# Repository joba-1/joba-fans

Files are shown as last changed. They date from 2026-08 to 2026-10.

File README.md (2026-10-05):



# joba-fans — quiet, networked fans for radiators

A small system that puts **PC fans on top of panel radiators** and controls them over WiFi. Its job is
to make a heat pump that cools through wall-hung radiators work properly: a low-mounted radiator hardly
emits any cooling power by free convection, so the heat pump short-cycles. Forced air over the fins
recovers a factor of roughly 3–4 (reasoning and sizing: [fan-mount/docs/requirements.md](fan-mount/docs/requirements.md)).

Four parts, each in its own directory with its own README:

| Part | What it is | Technology |
|---|---|---|
| [`fan-controller/`](fan-controller/) | The board: four PWM fan channels with tach read-back on a socketed ESP32 module | KiCad 10, Python generators |
| [`fan-housing/`](fan-housing/) | A snap-fit 3D-printed case for that board | OpenSCAD |
| [`fan-remote/`](fan-remote/) | The firmware: web remote, MQTT, Home Assistant discovery, soft start | PlatformIO / Arduino-ESP32 |
| [`fan-mount/`](fan-mount/) | 3D-printed mounts that hold 120 mm fans on the radiators | FreeCAD, STL |

## How it fits together

```mermaid
flowchart LR
  subgraph radiator["Radiator"]
    F["PC fans, 120 mm, 4-pin PWM<br/>in <b>fan-mount</b> parts"]
  end
  subgraph box["<b>fan-housing</b> (printed case)"]
    B["<b>fan-controller</b> board<br/>XIAO ESP32-C3<br/>running <b>fan-remote</b>"]
  end
  PSU["12 V supply"] --> B
  B -- "PWM 25 kHz, +12 V<br/>tach back" --> F
  B <-- "WiFi" --> N["Browser (web remote)<br/>MQTT broker + Home Assistant"]
  N -.-> HP["heat-pump / room control<br/>(outside this repo)"]
```

* A **radiator** carries up to ~9 fans in `fan-mount` parts. The fans are standard 120 × 25 mm PC fans.
* Each **controller board** drives four channels; several fans can share a channel (same speed, one tach).
  A 12 V supply feeds the board, which passes 12 V on to the fans.
* The **firmware** gives each board a web page, MQTT topics and a Home Assistant device. Speeds are set
  there — by hand, or by automation (for instance a heat-pump cooling signal in Home Assistant). The
  temperature logic is deliberately *not* part of this repo; the firmware only exposes the fans.
* The **housing** protects the board and brings the barrel jack, USB-C port and four fan cables out.

### The interfaces, and how each was checked

| Interface | Contract | Checked |
|---|---|---|
| firmware ↔ board | FAN1–4: PWM on D1/D3/D7/D6, tach on D2/D4/D10/D5 (GPIO 3/5/20/21 and 4/6/10/7) | The pin table in `fan-remote/src/Fans.cpp` equals the pad nets read out of `fan-controller.kicad_pcb`; the firmware builds for the XIAO ESP32-C3 and C6 and its 22 unit tests pass |
| board ↔ fans | 4-pin PC fan, pinout GND / +12 V / tach / PWM, 25 kHz PWM, 3.3 V logic | Pinout equals the PCB nets of J2–J5; 25 kHz is what the firmware generates. Total current of all fans must stay below the 1.5 A polyfuse |
| board ↔ housing | outer dimensions, connector positions, USB-C end, jack overhang | `fan-housing/board_params.scad` is regenerated from the PCB and is identical; `check_fit.py` passes (latch strain 1.5 %, ≥ 2.2 mm of air above every part, no tab hits a component); the STLs match the OpenSCAD source; the USB-C cut-out sits at the module's USB end (the module's pad rows run along the board's short side, with D6/D7 and the antenna at the other end) |
| fans ↔ mounts | 120 mm fan, 25 mm thick, 105 mm hole pattern | Collar inside 120.6 mm, rest height 2 mm, collar 28 mm; STL sizes match the spreadsheet dimensions (226.6 × 126.6 × 28 mm) |
| firmware ↔ Home Assistant | MQTT discovery, topics `fan-control/<id>/…` | Tested on a bench board with HA (see `fan-remote/docs/test.md`) |
| housing ↔ mounts | none (they only meet through the fans and cables) | — |

Fitting the parts together turned up four things worth knowing; all are written down in the component
READMEs:

1. The fan headers on the board are **unshrouded** — a reversed connector puts 12 V on a tach line
   ([fan-controller](fan-controller/README.md#known-issues)).
2. The PWM lines **float during an ESP reset**, so fans can burst briefly (also fan-controller; a pull-down
   is a candidate for board revision 2).
3. A radiator needs **more fans than a board has channels**, so fans must be chained per channel
   ([fan-mount](fan-mount/README.md#how-it-fits-the-rest-of-the-system)); this has not been tried yet.
4. The firmware has not yet run **on the real board** — only on a bench XIAO with one fan.

## Building it

1. **Board.** Order from the files in [`fan-controller/fab/`](fan-controller/fab/) (a PCB service that does
   assembly; revision 1 went to PCBWay), or regenerate them with `fan-controller/scripts/make_fab.sh`.
   Plug a XIAO ESP32-C3 into the sockets.
2. **Case.** Print the three STLs from [`fan-housing/stl/`](fan-housing/stl/) (PETG, no supports).
3. **Mounts.** Pick the variant for your radiator in [`fan-mount/cad/`](fan-mount/cad/) (the radiator
   sheet geometry is in [`fan-mount/docs/measurements.md`](fan-mount/docs/measurements.md)) and print it in
   PETG. Measure your own radiator first if it differs from the three documented ones.
4. **Firmware.** Register the board and flash it over USB-C, then set WiFi and the MQTT broker in the
   board's setup portal — see [`fan-remote/README.md`](fan-remote/README.md).
5. **Assemble.** Fans into the mounts and onto the radiator, fan cables into the board's headers (check
   that pin 1 = GND), board into the case, 12 V in.

## Repository layout

```text
fan-controller/   KiCad project, generator scripts, fab/ (fabrication package), docs/ (build log)
fan-housing/      OpenSCAD case, STLs, fit check
fan-remote/       PlatformIO firmware, tests, docs/ (spec, user, admin, test)
fan-mount/        FreeCAD models, STLs, scripts, docs/ (requirements, measurements, design notes)
assets/           logo (the fan symbol, also used as favicon) and social-preview image
LICENSE           CC BY-SA 4.0
```

Naming: the directories are named by role. The firmware names itself `fan-control-N` on the network (host
name, MQTT topics, Home Assistant ids) — that is the *device* identity, kept stable for boards that are
already installed, and is not the directory name.

## History and versions

Earlier, the board, the radiator mounts and the firmware lived in separate places. The commit history of
all of them is preserved here, now under the new directory names (messages are left in the language they were
written in, mostly German in the mounts' early history). Commit hashes changed in the merge, so documents
refer to **tags** instead:

| Tag | Meaning |
|---|---|
| `fan-controller-v1` | the board layout that was ordered (schematic and PCB unchanged since) |
| `fan-remote-v1.1.0` | firmware 1.1.0 (the firmware's build info is derived from `fan-remote-v*` tags) |

## Language and licence

Documentation and code comments are in English. Exceptions: the firmware's web page is bilingual
(German/English, by browser language), and the FreeCAD spreadsheets in `fan-mount/cad/` use German parameter
names (glossary in [fan-mount/docs/design-notes.md](fan-mount/docs/design-notes.md)).

[CC BY-SA 4.0](LICENSE). The XIAO symbol and footprints in `fan-controller/libraries/` come from Seeed
Studio's OPL_Kicad_Library, also CC BY-SA 4.0. The firmware pulls in third-party libraries through
PlatformIO under their own licences.

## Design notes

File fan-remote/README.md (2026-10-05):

# fan-remote

Firmware for the four-channel fan controller board in [`../fan-controller/`](../fan-controller/) (XIAO
ESP32-C3), part of the [joba-fans](../README.md) project. One board drives four 4-pin PC fans with 25 kHz
PWM and reads their RPM.

**Status:** version 1.1.0 (git tag `fan-remote-v1.1.0`), running on two boards. Unit tests pass on the PC and the image builds for
the XIAO ESP32-C3 (the module the board is designed for) and the pin-compatible ESP32-C6. It has been run
on a bench C6 with one fan; the hardware bring-up on the real fan board is still open (see
[docs/test.md](docs/test.md)). The pin table matches the board's pad nets.

* **Web remote** on every board (`http://fan-control-1/`): live RPM, on/off, preset
  speeds, a free slider, per fan and for all fans. Phone first, German and English.
* **Safe, quiet start.** The duty is raised slowly until the tach shows the fan
  turning, then slewed to the target; a blocked fan is detected and retried with
  backoff instead of being driven hard.
* **MQTT** with **Home Assistant discovery**; any number of boards, one image.
* **Each board has its own colour** on the web page (from its number), so several controllers can be told apart.
* **Status LED** where the module has one (XIAO ESP32-C6): fans on/off and a health signal, dimmed at night, or dark.
* Fans keep running without WiFi, broker or browser: control runs in its own task.

```text
docs/spec.md    architecture, decisions and their reasons, topic reference
docs/user.md    using the web page and Home Assistant
docs/admin.md   building, flashing, provisioning, operations, troubleshooting
docs/test.md    test plan and the hardware bring-up checklist
```

## Quick start

```sh
pio test -e native      # unit tests, no hardware
pio run -e xiao_c3 -t upload   # first flash over USB-C
```

Boards are numbered in `devices.csv` (MAC → number): register a new one first, then flash.
The number is the host name (`fan-control-N`), the MQTT topic and the Home Assistant id.

```sh
python3 scripts/register_device.py --port /dev/ttyACM0     # prints fan-control-N
```

The first build creates `config.ini` (gitignored) with a random admin password and prints it.
That one password does the settings login, the setup access point and OTA. A fresh board opens the access point
`fan-control-N-setup`; join it and enter WiFi, name and broker. Later updates go over WiFi:

```sh
pio run -e ota -t upload --upload-port fan-control-1     # no firewall port needed
```

Details in [docs/admin.md](docs/admin.md).

## Layout

| Path | |
|---|---|
| `lib/FanCore/` | hardware-free logic (state machine, speed mapping, RPM): unit tested |
| `src/` | firmware: `Fans` (PWM, tach, task), `Web`, `Mqtt`, `Net`, `NetLog`, `Settings` |
| `web/` | the page (`index.html`, gzipped and embedded at build time) and `logo.svg` |
| `scripts/mock_server.py` | fake device API to work on the page without hardware |
| `test/` | Unity tests |

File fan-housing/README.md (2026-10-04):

# fan-housing — case for the 4-channel fan controller

A snap-fit case for the [`fan-controller`](../fan-controller/) board, no screws. Outer size
**78.5 × 30.6 × 28.2 mm**, parametric in OpenSCAD.

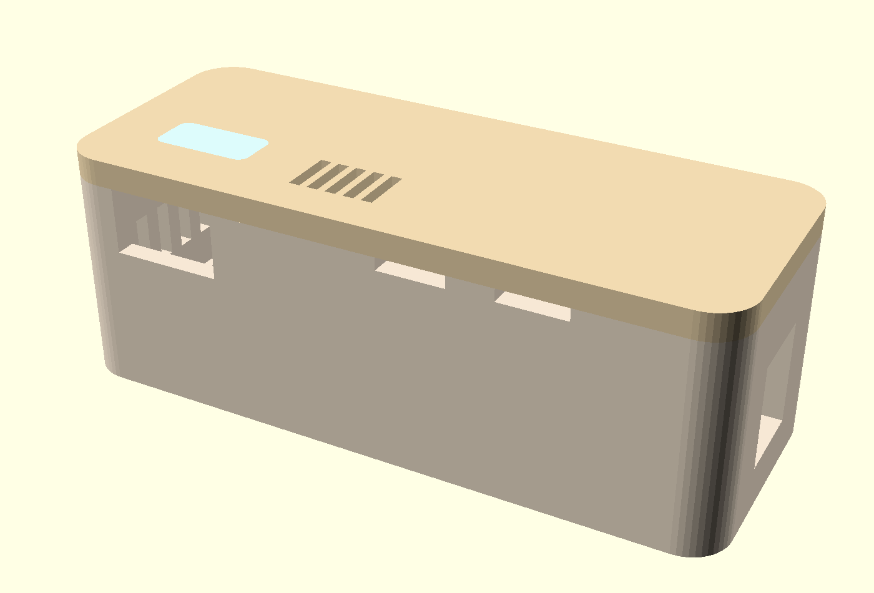
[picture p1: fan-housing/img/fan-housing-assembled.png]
Closed case


At the front the two cable slots for FAN1 and FAN2 and, to the left of them, the USB-C cut-out; at the
right the barrel jack; on top the light window and the vent slots above the voltage regulator. The other
two cable slots are mirrored on the back.

Generated from `fan-housing.scad`; all board dimensions come from `board_params.scad`, which
`extract_geometry.py` pulls out of the `.kicad_pcb`. The board is ordered and its dimensions are fixed —
only the case changes from here on.

## Parts

| File | Material | Position on the bed |
|---|---|---|
| `stl/fan-housing-tray.stl` | cream PETG | as exported, floor down; has four **mouse ears** (see below) |
| `stl/fan-housing-lid.stl` | cream PETG | as exported, visible face down, tabs up |
| `stl/fan-housing-guide.stl` | transparent PETG | as exported |

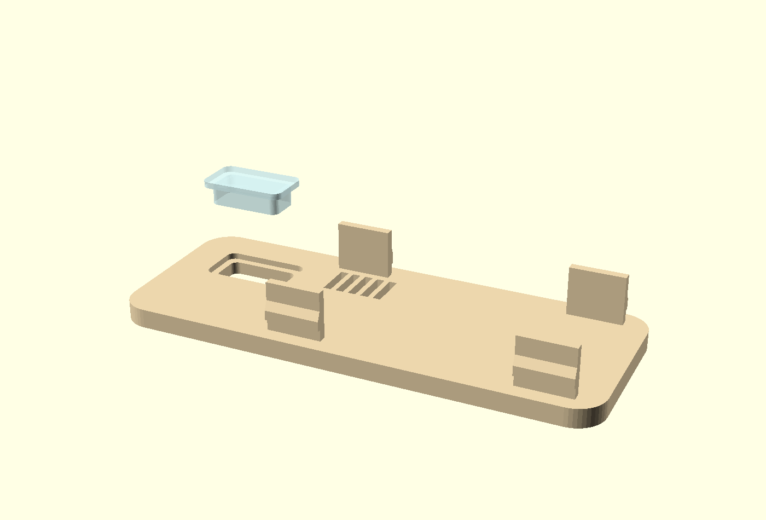
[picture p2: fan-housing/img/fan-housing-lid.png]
Lid in print orientation with light guide


The lid in print orientation — upside down, the four spring tabs pointing up. The latch nose can be seen
as a step on the two front ones; the chamfer below it pushes the tab in by itself when the lid is put on.

The light guide is shown lifted off and is **printed separately** — transparent, while the lid stays
cream. It is inserted from the inside of the lid, in this upside-down position from above. Its collar then
rests against the underside of the lid and keeps it from falling out.

**Printing lid and light guide in one multi-colour job** works, with two caveats found the hard way. The slicer
refuses the job (`gcode path conflicts … found slicing result conflict`) if the guide's collar overhangs the window by
more than about 1 mm (`guide_collar_o`, now 1.0), and — for reasons not understood — also for some positions on the
plate (e.g. at the far front right). Keep lid and guide as one group, so they keep their positions to each other, and
check that the slicer accepts the placement; turning the lid and guide together by 90° and putting them left of the
tray did it here.

All three are already exported in print orientation and need **no supports**. The lid lies upside down so
the visible face comes smoothly off the bed and the latch tabs point up.

Recommendation: 0.2 mm layers, 4 perimeters, and a **large brim** for the tray (8–10 mm, or keep the
mouse ears and add a brim around them). The four perimeters are not cosmetic — the spring tabs are
1.4 mm thick and should consist of perimeters, not infill.

## Assembly

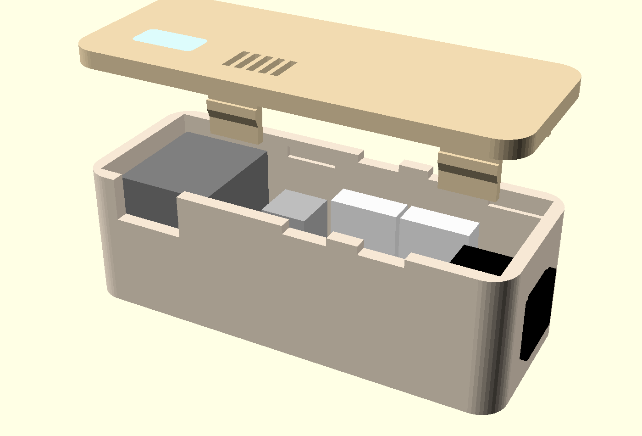
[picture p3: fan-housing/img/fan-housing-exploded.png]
Exploded view


1. Press the light guide into the lid opening from the **inside**. The collar holds it against the
   underside of the lid; it sits tight, but a drop of glue on the collar does no harm.
2. Put the board into the tray from above; it rests on the surrounding shoulder. 2.5 mm remain under it for
   the solder joints.
3. Plug in the fan connectors and lay the cables into the notches of the long walls. The notches are open
   at the top so that you lay the cables in instead of threading them — the connector does not fit through
   a closed hole. They are only 1.5 mm deep: the lid holds the cable lightly, which is also the strain relief.
4. Press the lid on until the four noses click in. To open, press the long walls outward a little at the
   latch points (at X 27.5 and 67 mm).

## Openings

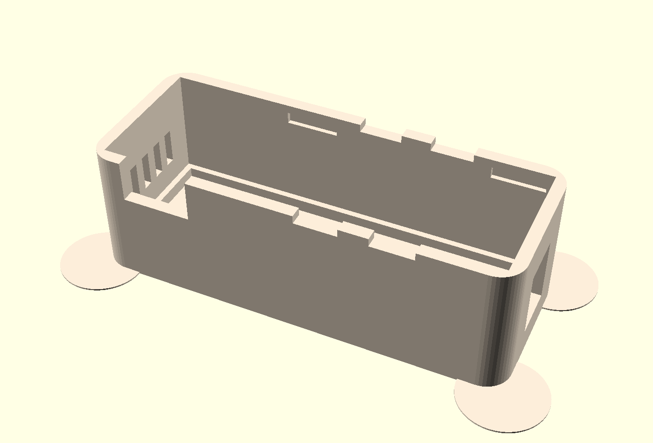
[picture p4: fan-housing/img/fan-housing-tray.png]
Tray from the inside


The inside is **sharp-cornered**, like the board (only the outside is rounded). The board has 0.4 mm
clearance (`fit`) to the walls on all four sides. Inside, the support shoulder for the board runs all around; below it 2.5 mm remain for the solder joints.
At the top of the long walls sit the four latch pockets as shallow recesses — they only mill into the wall,
a through-cut would be visible from outside. On the left the vent slots.

* **Barrel jack:** right end wall. It overhangs the board edge anyway and so sticks out of the wall. The
  opening is the jack's width minus `jack_trim` = 1.4 mm on each side.
* **Four cable notches**, 8 mm wide and 1.5 mm deep (`notch_depth`; the cable is 0.9 mm), above the fan connectors in the long
  walls. The lid closes them at the top; the cable is then captive.
* **USB-C** in the lower long wall, for re-flashing without opening: a closed window `usb_h` = 8 mm high
  (the plug's overmold, not just the 3.3 mm receptacle, has to fit), 13 mm wide, centred on the receptacle
  of the socketed XIAO. Can be switched off with `usb_opening = false`.
* **Vent slots** in the left end wall and in the lid above the AMS1117. At a 12 V input it dissipates about
  0.7 W; in a tight box this size that becomes noticeable. Can be switched off with `vents = false`.
* **Light window** in the lid above the XIAO — see below.

## Keeping the tray on the bed

A long, tall, thin-walled PETG tray shrinks while it cools and peels up at its ends. Two measures, one by
construction and one in the slicer:

* **Mouse ears** (`ears = true`): four 8 mm radius, one-layer (0.3 mm) discs centred on the bottom corners
  of the tray — they are part of `fan-housing-tray.stl` and add bed contact exactly where the lifting starts.
  Cut them off with a knife after printing; the tray's own walls are untouched. Set `ears = false` and
  re-export for a clean model.
* **A large brim** (8–10 mm) on top of that, a clean and warm bed (PETG: ~80 °C), no part-cooling fan for
  the first layers, and no draught. If it still lifts, the next step by construction would be to open the
  floor (slots) to relieve the stress — not done yet because it also reduces the bed contact.

## Dimension chains on layer boundaries

The lid is **3.1 mm** thick, not 3.0. The reason is not visual but about printing: with a 0.3 mm first layer
and 0.2 mm layers after that, the layer boundaries are at 0.3 / 0.5 / … / 2.9 / 3.1. A top edge at 3.0 falls
in the **middle** of a layer.

This only becomes apparent where two parts meet there: the collar of the light guide begins at the inside of
the lid, and at 3.0 mm the top of the lid and the underside of the collar claim the same layer at the same
place. The slicer then aborts with `found slicing result conflict` although the geometry is clean.

It was found on the printed part: the window sat one layer too far back on the inside. With 3.1 mm the
dividing plane lies on a layer boundary and the collar can be printed along.

**Rule of thumb:** where two parts in one print meet, the dividing plane must lie on a layer boundary.
Otherwise they compete for the same layer.

## About the LED

The XIAO ESP32-C3 has **no usable LED**: neither a power nor a user LED. The only LED on the module is the
charge indicator next to the USB-C socket, and it only lights when a LiPo is charging on the BAT pads. Our
board has no battery and no LED of its own. The window therefore stays dark unless something is retrofitted.
(The firmware does not drive an LED either.)

Retrofitting takes two components. The strapping pins D0 (pin 1), D8 (pin 9) and D9 (pin 10) are free — they
were deliberately left unconnected. **D8** is the right choice:

```text
3V3 (pin 12) --- 330 ohm --- LED --->|--- D8 (pin 9)
```

The LED lights when the firmware pulls D8 LOW. GPIO8 has to be HIGH during boot — in this circuit the LED is
then off, and the resistor to 3V3 additionally acts as a weak pull-up. The other way round (LED to GND)
would disturb booting.

Pins 9 and 12 are both in the left socket strip, 7.6 mm apart. The LED itself goes on top of the XIAO module
with two thin wires, under the window. 330 ohm are lying around anyway — it is the value of R9 to R12.

If you do not want that, set `light_window = false` and get a closed lid.

## Why the lid is 3 mm thick

The walls are 2.4 mm, the lid 3.1 mm. Cream PETG is still slightly translucent at 2.4 mm; an LED directly
underneath shows as a blotch. At 3 mm all is calm, and the light exits only where it should — through the
transparent light guide.

## Check before printing

The board dimensions are exact. The component heights are measured or catalogue values: socketed XIAO
module underside 12.5 mm above the board (**measured on the real assembly**; a plain 8.5 mm header was assumed
at first), XIAO board 1.0 mm, USB-C socket 3.3 mm (catalogue), fan connector 12.0 mm (a figure supplied by
the owner), electrolytic cap 12.5 mm. That gives 19 mm of inner height with a margin of 2.2 mm above the
tallest part (the XIAO).

If a value turns out to be different: adjust `h_socket`, `h_xiao_pcb`, `h_usbc` and `inner_h` in
`fan-housing.scad`, run `check_fit.py` and export again.

## Changing and checking

```sh
python3 fan-housing/extract_geometry.py   # after a change to the board (needs KiCad's pcbnew module)
python3 fan-housing/check_fit.py          # check the fits numerically (needs openscad)
fan-housing/export_stl.sh                 # regenerate the three STLs
```

`check_fit.py` checks what a render does not show: whether the latch nose hits its pocket, whether the
spring tab withstands the deflection (outer-fibre strain below 3 %, PETG yields from about 4 %), whether a
tab pokes into a component, and whether every component fits under the lid. Two errors have already
accumulated here that were not visible in the picture: a latch pocket that cut through the wall, and a nose
that sat 2 mm below its pocket. The model works out its cuboids itself and prints them via `echo()` so that
the dimensions do not live in two places.

Verified when this repository was assembled: `board_params.scad` is identical to what the current PCB
produces, `check_fit.py` passes all checks, and the three STLs match the OpenSCAD source (same bounding box
and volume).

For viewing: `part = "all"` (the default) shows the assembly with a solid tray and a **translucent lid** — look
down through the lid at the board with its parts (socketed XIAO with its USB-C receptacle, fan connectors, jack,
capacitor) to check the openings against the real parts (`board_mock(a)` sets the board's opacity):

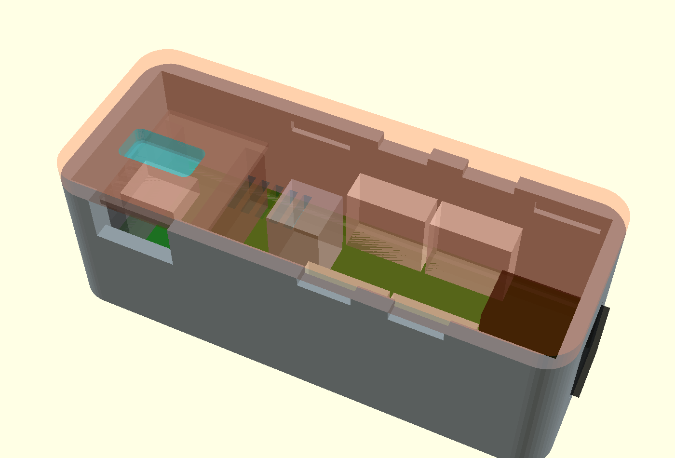
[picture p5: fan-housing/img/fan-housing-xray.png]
See-through view


Other views: `part = "explode"` shows the assembly with the lid
lifted off, `part = "closed"` the closed case, `part = "lid_guide"` the lid in print orientation with the
light guide lifted off. `part = "latch"` cuts a 5 mm thick slice across one latch and puts it at the origin
— for judging the engagement in the OpenSCAD GUI, where you can rotate freely. As a still image that is of
little use: from the inside the tab hides exactly the pocket, and the view from outside needs the CGAL
renderer, which ignores `color()`.

The pictures in `img/` are made in preview mode (without `--render`), otherwise all parts are one flat
yellow:

```sh
openscad -o img/fan-housing-assembled.png --imgsize=1400,950 \
         --camera=36.4,12.5,8,60,0,28,168 -D 'part="closed"' fan-housing.scad
```

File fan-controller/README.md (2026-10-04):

# fan-controller — 4-channel PWM fan controller board

A small two-layer board that drives **four 4-pin PC fans** (25 kHz PWM, tach read-back) from a socketed
**Seeed XIAO ESP32-C3**. 12 V in through a barrel jack, 72.9 × 25.0 mm. It is the electronics of the
[joba-fans](../README.md) project; the firmware that runs on it is [`fan-remote`](../fan-remote/), the case
is [`fan-housing`](../fan-housing/), and the fans sit in the [`fan-mount`](../fan-mount/) parts.

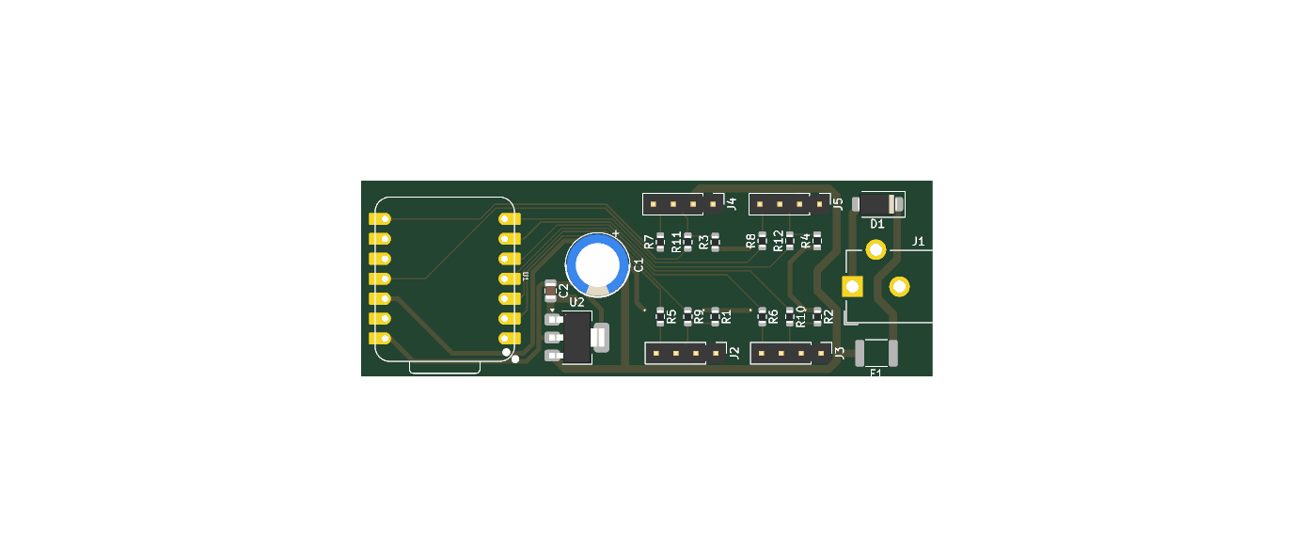
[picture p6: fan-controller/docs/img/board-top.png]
Board, top


**Status:** revision 1 (git tag `fan-controller-v1`) was ordered from PCBWay, 10 boards, fully assembled
except for the XIAO module (the story is in the [build log](docs/build-log.html)). The firmware has so far
been tested on a bench XIAO with one fan, not yet on this board — see
[`fan-remote/docs/test.md`](../fan-remote/docs/test.md).

## Circuit

Per channel the PWM goes through 1 kΩ to the fan, and the tach signal comes back through 330 Ω to the ESP,
with a 10 kΩ pull-up to 3V3. Supply is a barrel jack, an SS34 diode as reverse-polarity protection, a 1.5 A
polyfuse and an AMS1117-5.0 for the ESP (which also provides the 3V3 for the tach pull-ups). The XIAO module
is **socketed** (two 1×7 female headers), not soldered.

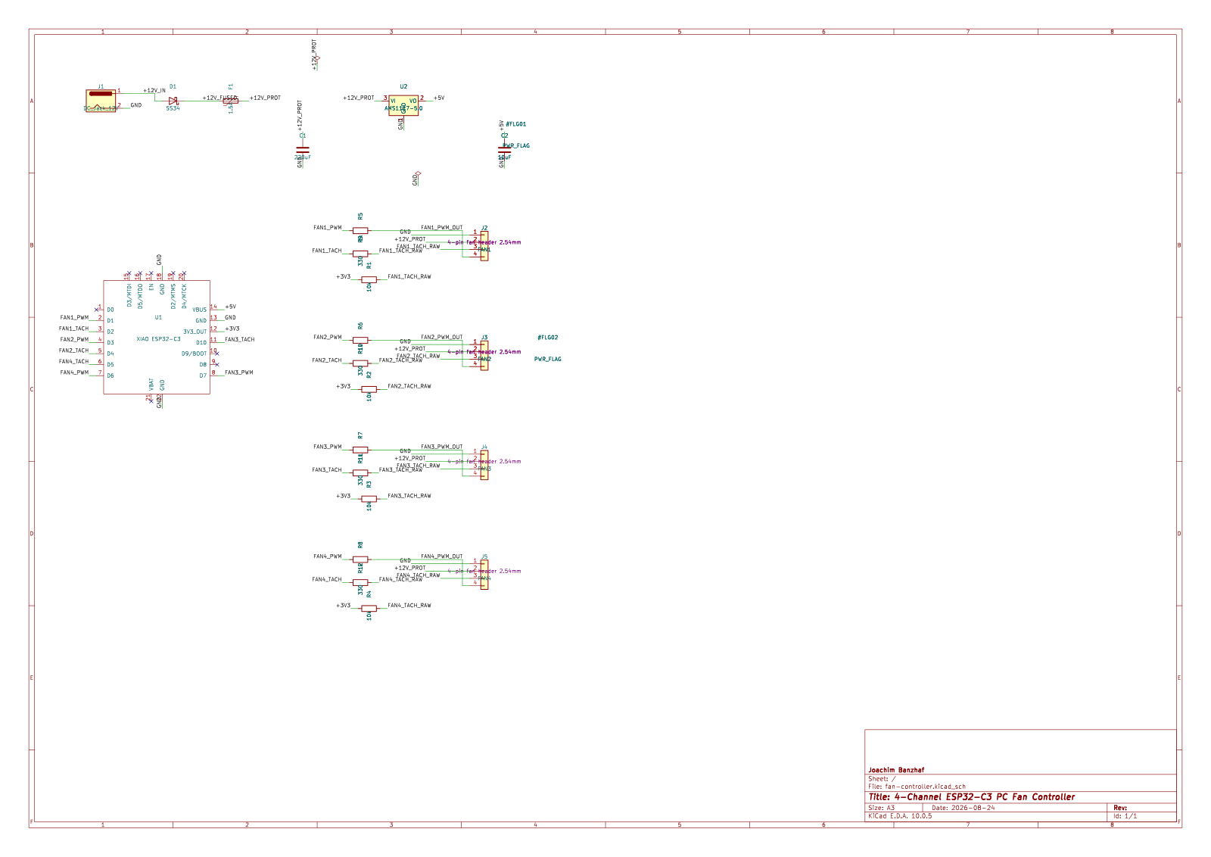
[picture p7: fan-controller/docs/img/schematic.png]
Schematic


### Pin assignment (verified against the PCB)

| Fan | Header | PWM (XIAO pin → GPIO) | Tach (XIAO pin → GPIO) |
|---|---|---|---|
| FAN1 | J2 | D1 → GPIO3 | D2 → GPIO4 |
| FAN2 | J3 | D3 → GPIO5 | D4 → GPIO6 |
| FAN3 | J4 | D7 → GPIO20 | D10 → GPIO10 |
| FAN4 | J5 | D6 → GPIO21 | D5 → GPIO7 |

D0, D8 and D9 are left free — strapping pins of the ESP32-C3 (D8 is suggested for an optional LED, see
[`fan-housing`](../fan-housing/README.md#about-the-led)). The firmware uses exactly this table
(`fan-remote/src/Fans.cpp`); both were checked against the pad nets of the `.kicad_pcb`.

Fan connector pinout (standard PC 4-pin): **1 = GND, 2 = +12 V, 3 = tach, 4 = PWM**.

| Part | Value |
|---|---|
| J1 | DC barrel jack 5.5 × 2.1 mm, 12 V, overhangs the board edge on purpose |
| D1 | SS34, reverse-polarity protection |
| F1 | 1.5 A polyfuse (1812), shared by all four fans and the regulator |
| U2 | AMS1117-5.0 for the XIAO's VBUS pin |
| C1 / C2 | 220 µF electrolytic (leaded, 3.5 mm pitch) / 10 µF 0805 |
| R1–R4 / R5–R8 / R9–R12 | 10 kΩ tach pull-up / 1 kΩ PWM series / 330 Ω tach series |
| J2–J5 | fan headers, 1×4, 2.54 mm |
| U1 | XIAO ESP32-C3 on two 1×7 female headers (the XIAO ESP32-C6 is pin-compatible) |

## Files

| Path | Content |
|---|---|
| `fan-controller.kicad_pro/_sch/_pcb` | the KiCad 10 project (open the `.kicad_pro`) |
| `libraries/` | XIAO symbol and footprints, vendored (see its README for the licence) |
| `scripts/` | Python tools: the schematic is **generated** from `netplan.py` by `generate.py`, the fab files by `make_fab.sh` |
| `fab/` | fabrication package: BOM and pick-and-place for JLCPCB and PCBWay, ordering notes, [fab/README.md](fab/README.md) |
| `docs/build-log.html` | the project page: from the discarded 555 sketch to the order (open in a browser; self-contained) |
| `docs/img/` | renderings of the schematic and the board |

## Working with the project

Regenerate the schematic from the net plan (also checks the exported netlist against the plan — ERC alone
does not find a wire that ends on the wrong pin):

```sh
python3 fan-controller/scripts/generate.py fan-controller/fan-controller.kicad_sch
```

Regenerate the fabrication data (needs `kicad-cli`; gerbers, drill, BOM and CPL in JLCPCB and PCBWay formats,
packed into `fab/fan-controller-fab.zip`):

```sh
fan-controller/scripts/make_fab.sh
```

Checked when this repository was assembled with KiCad 10: ERC 0 violations, DRC 0 violations and 0
unconnected pads; the generator reproduces the schematic (apart from random UUIDs) with all 22 nets matching
the plan; `make_fab.sh` reproduces the tracked BOM and CPL byte for byte.

Ordering: [fab/ORDERING.md](fab/ORDERING.md) (options and decision), [fab/ROTATION-WARNING.md](fab/ROTATION-WARNING.md)
(check D1 and U2 in the assembly preview), [fab/THT-ORDER-LIST.md](fab/THT-ORDER-LIST.md) (parts to source
yourself when the fab does not fit the through-hole parts).

## Known issues

* **The fan headers are unshrouded and unpolarised.** A fan connector plugged in the wrong way round puts
  +12 V on the tach net (header pin 3), which goes through only 330 Ω to an ESP32 GPIO. Check the orientation
  (pin 1 = GND) every time, or fit shrouded/keyed headers when building more boards.
* **The PWM lines have no pull-down.** While the ESP resets (power-up, OTA reboot, watchdog) the pins float and
  a fan's own pull-up asks for full speed — a short burst of up to a few tenths of a second. The firmware
  drives the pins low first thing; fixing it fully would take a 10 kΩ pull-down per line (board revision 2).
* **Total current:** the single 1.5 A polyfuse protects all four fan headers together. Add up the nameplate
  currents of the fans on a board (chaining several fans on one header is possible, see
  [`fan-mount`](../fan-mount/README.md#how-it-fits-the-rest-of-the-system)) and stay below that.
* **Jack and USB-C together:** the XIAO's VBUS pin is fed from the AMS1117; whether the module isolates its
  own USB 5 V from that pin has not been verified here. Flash over USB with the 12 V jack unplugged, or use
  the over-the-air update.

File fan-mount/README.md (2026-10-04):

# fan-mount — radiator fan mounts

3D-printed mounts that hold 120 mm PC fans on top of a panel radiator and blow down through its
convector channel. They are the "load" of the [`fan-controller`](../fan-controller/) board: the
fans sitting in these mounts are what the board drives.

**Why:** a heat pump that cools through wall-hung panel radiators short-cycles, because a radiator
mounted low on the wall hardly emits any cooling power by free convection (cold air sinks and
puddles around it). Forced air over the fins recovers a factor of roughly 3–4. The full reasoning,
the airflow decision and the sizing are in [docs/requirements.md](docs/requirements.md).

## Status

| Part | State |
|---|---|
| P1 fan mount (collar, ribs, baffles, pegs), variants **Small / Medium / Large** for three radiator types | modelled, trial prints made; STLs in `cad/` |
| Finger-guard hood, one variant for all mounts | modelled; STL in `cad/` |
| P2 blanking tiles, P3 discharge deflector, P4 cable clip | **not built** (concept only, see requirements) |
| Fixing | printed **pegs in the radiator slots**, screwed to the baffles — not the magnets of the original concept |
| 4th radiator (guest WC), tube and sectional radiators | not measured / out of scope for now |

The radiator measurements are partly still `open`; see [docs/measurements.md](docs/measurements.md).

## The three variants

Each fits one measured radiator sheet. The mount is a square collar for a 120 × 25 mm fan with four
corner rests, ribs on the unperforated edge strips, 50 mm baffles left and right, and pegs that
engage the radiator's top slots.

| STL | Radiator | Sheet depth | Fan seat |
|---|---|---|---|
| `cad/RadiatorFanSmall.stl` | A — office | 65 mm | asymmetric: the fan overhangs 41 mm to the front |
| `cad/RadiatorFanMedium.stl` | B — living room | 101 mm | centred |
| `cad/RadiatorFanLarge.stl` | C — dining room | 136 mm | centred, rib on the centre web, two perforated fields |
| `cad/RadiatorFanGuard.stl` | all | — | finger guard, slips over the collar |

The mounts are 226.6 mm wide (230 mm bed) and 28 mm tall; print flat, no support.
**Material: PETG** (or ASA) — PLA softens at around 60 °C, and the mounts sit on a heating radiator.
`cad/ZapfenLarge.stl` is a set of four spare pegs for radiator C.

## How it fits the rest of the system

* **Fans:** standard 120 × 120 × 25 mm, 105 mm screw pattern, 4-pin PWM. The collar is 120.6 mm
  inside, the fan sits 1 mm below its rim; the four ⌀6 mm holes take M4 screws with a washer.
  15 mm slim fans also fit and leave more intake space where the sill is low.
* **Controller:** each fan plugs into one of the four 4-pin headers of
  [`fan-controller`](../fan-controller/) (pin order GND, +12 V, tach, PWM). A radiator needs several
  fans (one per 250–300 mm of length), more than a board has channels, so the plan is to **chain
  2–3 fans per channel** with a PWM splitter cable: they then run at the same speed and only one
  fan's tach is read back (this chaining is not yet tried on the real board). Keep the
  *total* current of all four channels below the board's 1.5 A polyfuse.
* **Control:** [`fan-remote`](../fan-remote/) sets the speeds (web page, MQTT, Home Assistant). The
  mounts do not depend on it.

## Files

| Path | Content |
|---|---|
| `cad/` | FreeCAD documents (`.FCStd`, dimensions in the `Masse` spreadsheet), the print-ready STLs, `radiator_sheets.csv` |
| `scripts/` | FreeCAD scripts that build the parts from the spreadsheet |
| `docs/design-notes.md` | how the mounts were derived, print notes, glossary of the German parameter names, how to regenerate |
| `docs/requirements.md` | the original requirements and concept |
| `docs/measurements.md` | radiator measurements and the measurement checklist |
| `docs/primer.html` | illustrated primer for the concept (open in a browser) |

Not in the repository: the original photos (40 MB of phone HEIC) and G-code (regenerable from the
STLs).

## Regenerating a part

Open the `.FCStd` in FreeCAD, then in the Python console:

```python
ZIEL = "RadiatorFanLarge"
exec(open("<repo>/fan-mount/scripts/build_variante.py").read())
```

Details in [docs/design-notes.md](docs/design-notes.md). Parameter names inside the files are
German (`zarge`, `blende`, `zapfen` …); the glossary is there too.

## Known gaps

* Printed fit is only partly confirmed — the peg-in-slot fit (7.4–7.8 mm) is the first thing to check
  on the radiator; `zapfen_spiel` is the adjusting screw.
* The STLs are checked against the spreadsheet dimensions (sizes above), but were not regenerated
  from the scripts when the repository was assembled.
* Without a P2 blanking tile the top slot between fans is open, so part of the air spills back out;
  and in the heating season the fans should be turned over (see requirements C5).

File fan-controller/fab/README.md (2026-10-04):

# Fabrication package — 4-channel ESP32-C3 PC fan controller

Generated from `fan-controller.kicad_pcb` / `.kicad_sch` with KiCad 10.0.5.
Regenerate with `fan-controller/scripts/make_fab.sh` (from anywhere; needs `kicad-cli`).

## Board

| | |
|---|---|
| Size | 72.9 × 25.0 mm |
| Layers | 2 (F.Cu / B.Cu), 1 oz copper |
| Min track / clearance | 0.2 mm / 0.2 mm |
| Min drill | 0.3 mm |
| Finished thickness | 1.6 mm (standard) |
| Surface finish | HASL or ENIG, either is fine |
| Solder mask / silkscreen | any colour |
| Castellated / edge plating | no |

Quantity: the run that was ordered was **10 boards, assembled by PCBWay** (see the
[build log](../docs/build-log.html), stage 08). Earlier planning in `ORDERING.md` assumed 20.

## Contents

```text
gerbers/            RS-274X gerbers + Excellon drill (mm, absolute origin)  [generated, not in git]
  *-F_Cu.gtl          top copper
  *-B_Cu.gbl          bottom copper (ground plane)
  *-F_Mask.gts        top solder mask
  *-B_Mask.gbs        bottom solder mask
  *-F_Paste.gtp       top paste stencil
  *-B_Paste.gbp       bottom paste stencil
  *-F_Silkscreen.gto  top silkscreen
  *-B_Silkscreen.gbo  bottom silkscreen
  *-Edge_Cuts.gm1     board outline
  *.drl               drill file
  *-drl_map.gbr       drill map (reference only, do not fabricate)
  *-job.gbrjob        gerber job file
pcbway/                  BOM and CPL in PCBWay format (tolerant column
                         scheme, PTH listed for information)
THT-ORDER-LIST.md        through-hole parts to source yourself
                         (only needed with JLCPCB)
ROTATION-WARNING.md      check part rotation before ordering
fan-controller-bom.csv   BOM, JLCPCB columns (Comment, Designator,
                         Footprint, LCSC Part #)
fan-controller-cpl.csv   Pick and place, JLCPCB columns (Designator,
                         Mid X, Mid Y, Layer, Rotation); top side only,
                         DNP excluded
ORDERING.md              options compared, and the decision
```

The gerbers and `fan-controller-fab.zip` are regenerated by `make_fab.sh` and not tracked in git; the BOM and
CPL files are tracked (they are reviewable, and the BOM gets hand-edited for MPN / supplier columns).

Origin for both drill and placement files is the board's **bottom-left corner**.

## Assembly notes

The two fabs are served differently:

* **JLCPCB** — only the 16 SMD positions, solder THT yourself
  (`fan-controller-bom.csv`, `fan-controller-cpl.csv`)
* **PCBWay** — all 23 positions including the through-hole parts
  (`pcbway/`), since PCBWay offers through-hole assembly

**JLCPCB only assembles the 16 SMD positions.** The 7 through-hole designators (C1, J1, J2–J5, U1) are
removed from BOM and CPL — their catalogue does not carry them. They are sourced separately and soldered by
hand: specifications and quantities in **THT-ORDER-LIST.md**.

**U1 is the socket position, not the module.** Two **1×7 female headers** belong there; the XIAO module
itself is plugged in later and is not part of the assembly. The PCBWay BOM therefore says **Qty 2** — the
column means pieces per board, not number of designators. A hint in the Value field is not enough; the
calculation follows the column.

The reason for this twist: the sockets have no schematic symbol of their own — their holes are the 14
through-hole pads of the module footprint. As a BOM line of their own with invented designators (U1-SKT1/2)
they would have no CPL entry, and JLCPCB rejects BOM lines without a matching CPL entry. That is why the
position runs under U1, with the socket as the comment.

All parts are on the top side. J1 (barrel jack) overhangs the right board edge by design — its flange seats
on the edge so the socket is reachable from outside an enclosure.

The **LCSC Part #** column in the BOM is empty for some lines. Either fill it in yourself or let the
assembler substitute from stock — apart from the barrel jack and the AMS1117, everything is standard stock.

BOM and CPL are in **JLCPCB's column format**. kicad-cli exports its own headers
(`Ref,Val,Package,PosX,PosY,Rot,Side`, or `Value` instead of `Comment`), which their import rejects — which is
why `make_bom.py` and `make_cpl.py` convert the files. For PCBWay or Aisler both formats are generally fine.

JLCPCB matches **BOM and CPL designator by designator**. The BOM therefore contains complete comma lists
(`R1,R2,R3,R4`) instead of ranges (`R1-R4`), and every designator exists in both files. Currently 23 on both
sides, congruent.

## Reproducing

```sh
fan-controller/scripts/make_fab.sh
```

Gerbers must be exported with an explicit `--layers` list. A bare `kicad-cli pcb export gerbers` writes
*every* layer, including the `User.Eco1` scratch layer used during layout for review markers.

Checked when this repository was assembled: regenerating from the current board and schematic reproduces the
tracked BOM and CPL files byte for byte; ERC and DRC report 0 violations and 0 unconnected pads.

## LCSC part numbers

JLCPCB's matching guesses without a part number and usually does not find THT parts at all. The numbers are
therefore kept in `scripts/make_bom.py` (dict `LCSC`).

Confirmed — supplied by JLCPCB's own BOM matching, all Basic Parts:

| Pos | Part | LCSC |
|---|---|---|
| C2 | 10uF 0805 | C440198 |
| D1 | SS34 SMA | C8678 |
| U2 | AMS1117-5.0 SOT-223 | C6187 |
| R1-R4 | 10k 0603 | C25804 |
| R5-R8 | 1k 0603 | C21190 |
| R9-R12 | 330 0603 | C23138 |

Researched, **not** confirmed by JLCPCB — check against the catalogue before ordering:

| Pos | Part | LCSC | Note |
|---|---|---|---|
| F1 | SMD1812P150TF/24 | C209713 | 1.5A **24V**. The /8 variant (C209721) is only 8V and not enough for 12V. |
| U1 | female header 2.54mm 1x40 | C5303 | to be cut to 2x 1x7 |

Open — to be selected in the web interface:

* **J1** barrel jack 5.5x2.1mm horizontal
* **J2-J5** pin header 1x4 2.54mm
* **C1** 220uF electrolytic cap, **leaded**, pitch 3.5mm

On C1: JLCPCB suggested C2941234, an **SMD** electrolytic cap 6.3x5.8mm. It does not fit — our footprint has
leaded pads with 3.5mm pitch. Do not accept the suggestion.

JLCPCB reports the three resistor lines as "Unconfirmed" because the comment ("10k") is not the manufacturer
part number. The parts are right in substance; confirm in the web interface, otherwise the quantity stays at 0.

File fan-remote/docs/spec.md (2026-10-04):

# fan-remote — firmware for the 4-channel fan controller

Firmware for the XIAO ESP32-C3 on the `fan-controller` board (see [`../fan-controller/README.md`](../../fan-controller/README.md)).
One board drives up to four 4-pin PC fans. Several boards run side by side.

## Goals

1. Drive four fans with 25 kHz PWM and read back their RPM from the tach lines.
2. A one-page web remote: live RPM, on/off, preset speeds, a free slider, per
   fan and for all fans at once. Responsive, phone first.
3. **Safe and quiet switch-on**, also at low speeds (see "Fan control").
4. MQTT control and state, with Home Assistant MQTT discovery.
5. Any number of boards without per-board builds: one image, identity from `devices.csv` (MAC → number).
6. Low power in standby: full power for a minute after any interaction, then WiFi modem sleep and a lower CPU clock.

Non-goals: temperature control loops (that lives in Home Assistant / the heat-pump
tooling and talks to the fans over MQTT), cloud access, BLE.

## Hardware facts the firmware depends on

Verified against `fan-controller.kicad_pcb`, not just the net plan:

| Fan | PWM (via 1 kΩ) | Tach (330 Ω, 10 kΩ pull-up to 3V3) |
|---|---|---|
| FAN1 | D1 = GPIO3 | D2 = GPIO4 |
| FAN2 | D3 = GPIO5 | D4 = GPIO6 |
| FAN3 | D7 = GPIO20 | D10 = GPIO10 |
| FAN4 | D6 = GPIO21 | D5 = GPIO7 |

* The PWM output is a 3.3 V push-pull signal straight into the fan's PWM pin
  (Intel 4-wire spec: 25 kHz, 100 % duty = full speed, **not inverted**).
* There is no pull-down on the PWM lines. While the ESP32 resets (power-up, OTA
  reboot, watchdog) the pins float and the fan's own pull-up asks for full
  speed. The firmware drives the pins low as the very first thing in `setup()`,
  but the first ~0.3 s after a reset can still be a short burst. Not fixable in
  firmware; a 10 kΩ pull-down per line would be a board change.
* D6/D7 are the UART0 pins. The console is USB-CDC, so UART0 is unused, but the
  ROM boot log shows up as a few ms of noise on FAN4's PWM line.
* The ESP32-C3 has no PCNT unit; tach edges are counted in a GPIO interrupt.

## Architecture

```text
 web UI (SSE + REST) ─┐
 MQTT / HA discovery ─┼─> Fans (mutex) ──> FanCore::Channel x4 ──> LEDC PWM 25 kHz
 ArduinoOTA, syslog   ┘        ▲                                       │
                               └── tach ISR (edge count + timestamps) ◄┘ fans
```

* **`lib/FanCore`** — pure C++, no Arduino includes: the per-channel state machine
  (`Channel`), speed→duty mapping and the RPM estimator (`RpmMeter`). Tested on the
  PC (`pio test -e native`).
* **`src/Fans`** — owns the pins, the ISRs and a **dedicated FreeRTOS task** (20 ms
  tick, priority above `loop()`). *Decision:* fan control never shares a thread with
  WiFi, MQTT or the web server, so a blocked connect (WiFiManager, DNS, a slow TLS-less
  TCP timeout) can never freeze a ramp half-way. The network code only calls
  `setSpeed()` and reads snapshots.
* **`src/Settings`** — everything persistent lives in NVS (`Preferences`): identity,
  network targets, per-fan limits, presets, last speeds.
* **`src/Web`** — `ESPAsyncWebServer`; the page is one gzip-compressed HTML file
  embedded in the firmware image (`web/index.html`), so an OTA update is one
  artifact and there is no separate filesystem upload.
* **`src/Mqtt`** — `PubSubClient`, LWT, retained state, HA discovery.
* **`src/NetLog`** — Serial plus UDP syslog (RFC 3164) to the alias `syslog`.

### Decisions and reasons

| Decision | Why |
|---|---|
| Arduino + PlatformIO, not ESPHome | Plain Arduino-ESP32 code and libraries; the custom web UI and the spin-up logic would fight ESPHome's component model. |
| Fan task independent of the network | Safety: fans keep their last speed with no WiFi, no broker, no browser. |
| Speed 1…100 maps onto the *usable* duty range `[min, max]` per fan | "1 %" is the quietest speed that really runs; HA's percentage slider has no dead zone below the stall point. `0` is off. |
| Presets stored as speeds, edited in the UI | Fans differ; "Low" should be what the user finds quiet, not a fixed number. |
| Channel numbers 1…4 in topics and the UI | Matches the silkscreen (FAN1…FAN4). |
| Device id = `fan-control-N`, N from `devices.csv` (MAC → number), never reused | Readable, stable MQTT topics and HA unique ids instead of MAC digits; the friendly name is separate and renameable. An unregistered board runs as `fan-control-new-xxxxxx` so it is still unique and recognisable. |
| Friendly name starts as the id (`fan-control-N`); a fan without a name of its own has an empty name | The page labels it "Fan N" or "Lüfter N" by browser language, Home Assistant "Fan N". No language is baked into the stored data. |
| One admin password per build tree (random, in the gitignored `config.ini`) for settings, AP and OTA | Home network: a per-board secret to look up is more trouble than protection. Still HTTP Basic with a constant-time compare and a lockout; changeable per board via `/api/netconfig`. |
| Control endpoints open on the LAN, settings behind Basic auth | The remote must work from any phone without a login dance. `protectControl` turns the login on for control as well. Deviation from "UI needs auth" is limited to the LAN-only case. |

## Fan control

### Speed model

`speed` (user) 0…100. `0` = off. Otherwise `duty = min + (max − min) · speed / 100`
with per-fan `min` (lowest duty that keeps the fan turning, default 5 %) and `max`
(noise cap, default 100 %).

### Safe, quiet start

A fan standing still needs more torque to start than to keep running. A fixed
"kick to 100 %" is loud; starting at the target duty may never start. The firmware
searches instead:

1. Off → on: start at `startPct` (default 15 %, but never above the target) and
   raise the duty slowly (`spinupPctS`, default 8 %/s).
2. The moment the tach shows rotation (4 edges = 2 revolutions) the fan is **running**;
   the duty then slews to the target. Usually that is the quietest possible start
   and the fan never sees more duty than it needed.
3. The ramp is capped at `kickPct` (default 50 %, or the target if higher). If the
   cap is held for `spinTimeoutMs` without a tach edge, the fan is declared
   **stalled**: PWM goes to 0, the fault is reported (web, MQTT, HA) and a retry
   follows after 15 s, doubling to at most 5 min. A blocked or unplugged fan is
   therefore never driven hard indefinitely.
4. Fans without a usable tach signal (`tach = off`): there is nothing to detect, so
   the duty rises to `kickPct` (or target), holds for `blindKickMs`, then slews down.
5. While running, no tach edge for `stallMs` (5 s) while the target is above 0
   is the same fault → the same recovery.

All speed changes are slew-limited (`rampUpPctS` 10 %/s, `rampDownPctS` 20 %/s):
no sudden pitch changes in a living room. Turning off ramps down, then cuts the PWM.

### Web feedback

Input is acknowledged at once but never guessed: the control that was used gets a
"pending" marker (pulsing chip, spinner on the power button, dimmed number with a dot on
the slider). Speed, badge, RPM and the lit preset chip change only when the controller
reports them; the marker clears when the reported speed matches the request, or after 3 s
with a hint. The slider sends its first value immediately, then at most every 120 ms.

### Standby power saving

`power_save = 1` (default). Any user interaction (page load, command, settings, HA/MQTT
command, OTA, the page's `/api/wake` on touch) means **active**: CPU 160 MHz, WiFi awake.
`idle_seconds` (60) after the last one the board goes to **standby**: WiFi modem sleep,
CPU 80 MHz. It stays active while the setup portal is open or WiFi is down. Measured on
the bench board: active answers in 1…5 ms; in standby pings average ≈ 115 ms, and the
page's wake request (sent when a finger touches it) absorbs that, so the command that
follows takes ≈ 13 ms.

The floor is 80 MHz: WiFi needs it, and the LEDC PWM timer runs from the 80 MHz APB clock,
which CPU clocks ≥ 80 MHz leave alone. Checked on the C6 with a fan running: the PWM stays
at 25 000 Hz and the RPM does not change across the switch (`/api/netstatus` → `power.pwmHz`).
Not checked on a C3 yet. Fan control is not interaction: a running fan alone does not keep
the board awake. `power_save = 0` keeps full power always.

### RPM

Falling edges are counted in the ISR (glitches closer than 1.5 ms are ignored);
the ISR also stores the timestamp of the first and last edge of each 1 s window.
`rpm = (edges − 1) · 60 s / (span · pulsesPerRev)`. That is accurate at 300 rpm
(10 edges/s), where plain edge counting would be ±10 %.

### Persistence

The target speed per fan is written to NVS 5 s after the last change and restored
at boot (`bootMode`: `last` or `off`, default `last`). The restore goes through the
normal soft start.

## Interfaces

### Web

| Route | Auth | |
|---|---|---|
| `GET /` | – | the page |
| `GET /events` | – | SSE: `state` event (full state JSON) on every change and each second |
| `GET /api/state` | – | same JSON once |
| `POST /api/set` | optional | `ch=1..4|all`, plus `speed=0..100` **or** `preset=<id>` **or** `power=on|off` |
| `GET /api/config`, `POST /api/config` | Basic | per-fan limits and names, presets, ramps, bootMode, protectControl |
| `GET /api/netstatus` | – | firmware, version, build date, hostname, IP, SSID, RSSI, heap (`freeHeap`, `minFreeHeap`, `maxAllocHeap`), stack left per task (`stackLeft`: lowest free bytes ever of `async_tcp`, `loopTask`, `fans`), every external resource with host, last status, last access |
| `POST /api/netconfig` | Basic | `name`, `mqttHost`, `mqttPort`, `mqttUser`, `mqttPass`, `syslogHost`, `ntpHost`, `defaults=1`; stored in NVS, applied at next boot |
| `POST /api/update` | Basic | firmware image (multipart field `firmware`); written to the next OTA slot, validated, then reboot. The host connects out to port 80: no host firewall port needed (ArduinoOTA remains as a fallback) |
| `POST /api/discovery` | Basic | resend the Home Assistant discovery; `recreate=1` first removes the old entities and announces new ones under generation + 1 (unique ids and discovery topics carry `_gN`), so entity ids are rebuilt from the current names |
| `GET /api/wake` | – | the page sends it on touch; counts as an interaction and wakes the board from standby |
| `POST /api/reboot`, `POST /api/wifireset` | Basic | |

`netstatus` / `netconfig` give every external resource (broker, syslog, NTP) a host, a last status and a last access time, and keep the settings editable at run time.

### MQTT

Base `fan-control/<id>` (prefix configurable at build time). `<n>` is 1…4.

| Topic | Dir | Payload |
|---|---|---|
| `fan-control/<id>/status` | pub, retained, LWT | `online` / `offline` |
| `fan-control/<id>/<n>/speed/state` | pub, retained | `0…100` |
| `fan-control/<id>/<n>/speed/set` | sub | `0…100` |
| `fan-control/<id>/<n>/power/state`, `…/power/set` | pub / sub | `ON` / `OFF` (ON restores the last non-zero speed) |
| `fan-control/<id>/<n>/preset/state`, `…/preset/set` | pub / sub | preset id, or `None` |
| `fan-control/<id>/<n>/rpm` | pub | integer rpm, on change ≥ 10 rpm or every 30 s |
| `fan-control/<id>/<n>/fault` | pub, retained | `ON` / `OFF` (stalled) |
| `fan-control/<id>/all/speed/set`, `…/all/preset/set` | sub | all fans |
| `fan-control/<id>/info` | pub, retained | JSON: version, ip, rssi, uptime |

Home Assistant discovery (`homeassistant/…`, retained, re-sent on every connect):
one `fan` per enabled channel (on/off, percentage 1…100, preset modes), a `number` "speed"
slider (0…100 %, step 1, same topics as the fan's percentage), a `sensor`
(rpm) and a `binary_sensor` (problem) per channel, diagnostic sensors for RSSI and
uptime. All entities share one HA *device* per board.

Entity ids: Home Assistant restores the old entity id for a returning unique id (tested on 2026.9:
clearing and re-announcing, as Zigbee2MQTT's `homeassistant_rename` does, changes nothing). So the
unique ids carry a generation (`haGen` in NVS, 0 = plain ids); `/api/discovery?recreate=1` bumps it,
clears the old topics, waits 2.5 s (otherwise HA creates `_2` entities) and announces the new ones.

Credentials for the broker are stored in NVS, never in the repo.

## Safety / security

* Fans keep running on loss of WiFi / MQTT; the fan task has no network dependency.
* Task watchdog on; a stuck fan task reboots the board (fans then float → full speed
  briefly, see above; acceptable against a hung controller).
* All inputs validated (ranges, enum values, string lengths); no `String` building
  from request data into responses without JSON escaping (ArduinoJson).
* Settings, OTA and reboot need the admin password (Basic auth, constant-time compare; by default
  the random one from `config.ini`). OTA is password protected. No credentials in the repository:
  `config.ini` is gitignored, the template carries a placeholder that the first build replaces.
* MQTT commands can change speeds only — never network targets.

## Open points / future

* A pull-down on the PWM lines (board revision) to make reset quiet.
* Temperature-driven control belongs in HA; a simple "fan follows sensor X" blueprint
  can be added to `docs/` once real fans have been measured.

## Status LED and health

Optional; a build without `LED_FAN_PIN` has no LED code path. Pins and polarity are build flags in
`platformio.ini`: `LED_FAN_PIN` (+ `LED_ALERT_PIN` for a second LED) and `LED_ACTIVE_LOW`. The XIAO
ESP32-C6 build drives its yellow user LED (GPIO15, active low); the red LED beside it is the battery charge
indicator and is not under software control. The C3 build points at D8, the pin the housing README suggests
for a retrofitted LED (harmless without one).

**Health** is a bit mask (`netstatus.health`): a stalled fan, no WiFi, no MQTT (only if a broker is
configured), clock not synchronised. 0 = healthy.

| LEDs | Pattern |
|---|---|
| one | fans off, healthy: dark · fans on, healthy: steady · fans off, problem: 100 ms flash once a second · fans on, problem: blinking 2 Hz |
| two | first LED: fans on · second LED: problem |

**Brightness** is PWM (1 kHz, 10 bit), in percent: `ledDay` by day, `ledNight` at night (defaults 30 % and 5 %),
night = local hours `nightFrom`..`nightTo` (default 22..7, wraps over midnight). `ledMode` 0 switches the LED off
completely (dark operation). Without a synchronised clock it is always day. All of it is in `/api/config`
(`led`) and the settings dialog; defaults come from `config.ini`. The pure logic (night window, brightness,
patterns, health mask) is in `FanCore` and unit tested.

## Web page colour

The base hue of the page comes from the device number (`fan-control-N`, read from the host name first and
from the state's id after that): eight hues between blue and violet (190, 245, 285, 215, 265, 205, 295, 230°),
wrapping for N > 8. Red and green are the signal colours of the page (problem / ok) and stay fixed; the hue set
keeps clear of both. Board 1 keeps the original blue.

## Stack and heap budget

Measured on the real board with `/api/netstatus` (`stackLeft` is the lowest free stack since boot), after
state/config reads, a settings save, a Home Assistant discovery resend and a rejected firmware upload:

| Task | Stack | Lowest free | Used at most |
|---|---|---|---|
| `async_tcp` (all web handlers) | 16 384 B | 13 076 B | ~3.3 KB |
| `loopTask` (WiFi, MQTT, power) | 8 192 B | 5 216 B | ~3.0 KB |
| `fans` | 6 144 B | 5 740 B | ~0.4 KB |

Heap: about 278 KB free, lowest 253 KB since boot, largest allocatable block 245 KB. Re-check after
changes to the handlers or the discovery code (`curl http://fan-control-1/api/netstatus`).

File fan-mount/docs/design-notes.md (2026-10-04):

# fan-mount — design notes

How the mounts in `../cad/` were derived, why they look the way they do, and how to regenerate
them. The requirements are in [requirements.md](requirements.md), the measured radiator data in
[measurements.md](measurements.md).

## What is in `cad/`

| File | Content | Status |
|---|---|---|
| `RadiatorFanSmall.FCStd` / `.stl` | Mount for radiator **A** (office, 65 mm deep sheet), asymmetric seat | current |
| `RadiatorFanMedium.FCStd` / `.stl` | Mount for radiator **B** (living room, 101 mm), fan centred | current |
| `RadiatorFanLarge.FCStd` / `.stl` | Mount for radiator **C** (dining room, 136 mm), two perforated fields, rib on the centre web | current |
| `RadiatorFanGuard.FCStd` / `.stl` | Finger-guard hood, **one variant for all mounts** (it only depends on the collar, 126.6 mm) | current |
| `ZapfenLarge.stl` | Four pegs for radiator C, printed on their own | current |
| `passprobe.FCStd`, `passprobe_A/B/C.stl` | Fit-test frames: do the measured sheet depths and the edge grip work? | test part |
| `halter_A.stl`, `halter_A_komplett.stl` | First design of the mount for radiator A (mount alone / mount + 6 pegs) | superseded by `RadiatorFanSmall`, kept for reference |
| `radiator_sheets.csv` | Measured perforated-sheet geometry of the three radiators — the source of truth for the spreadsheets | data |

Every `.FCStd` has a spreadsheet **`Masse`** (dimensions) that drives all geometry; a few cells are
formulas (derived values). `Small`, `Medium` and `Large` are the same document with different inputs.

The parts inside are called `Halter` (mount: collar + ribs + baffles), `Zapfen` (pegs), `Schutz`
(guard) and `Zarge` (the collar around the fan).

### Sizes (checked against the STL files)

| | X | Y | Z | Derived from |
|---|---|---|---|---|
| Mount Small / Medium | 226.6 | 126.6 | 28.0 | `z_aussen` + 2 × `blende_b` = 126.6 + 100; `z_hoehe` = 2 + 26 |
| Mount Large | 226.6 | 134.0 | 28.0 | sheet depth 2·16 + 2·40 + 22 = 134 |
| Guard | 131.6 | 131.6 | 14.5 | `z_aussen` + 2 × `schutz_dicke` = 126.6 + 5 |

The fan seat is `z_innen` = 120.6 mm square (120 mm fan + 0.6 mm clearance); the collar is 26 mm
tall above the 2 mm fan rests, so a 25 mm fan sits 1 mm below the rim. The four screw holes use the
standard 105 × 105 mm pattern (`schraub_lk`). The guard's inner size equals the collar's outer size, so
it slips over the collar.

## Glossary of the German names

The spreadsheet aliases and the local variables in the scripts are German. They are stored inside
the `.FCStd` files, so they were not translated:

| Name | Meaning |
|---|---|
| `Masse` | the dimensions spreadsheet |
| `tiefe`, `a_tiefe` … | depth of the perforated sheet (A/B/C) |
| `rand`, `lochfeld`, `stegmitte`, `schlitz`, `steg` | edge strip, perforated field, centre web, slot, web between slots |
| `lueftergroesse`, `luefterhoehe` | fan size (120) and fan thickness (25) |
| `zarge` (`z_innen`, `z_aussen`, `z_dicke`, `z_hoehe`, `zarge_innen`) | the collar: inner/outer size, wall, total height, inner height above the rests |
| `z_auflage`, `z_ecke` | fan rests: thickness (2) and corner length (14) |
| `a_hinten`, `a_vorne`, `a_ueber` | how far the fan projects beyond the sheet: behind (wall side), in front, total |
| `wandabstand`, `wandluft_ist` | distance sheet–wall, resulting air gap to the wall |
| `rippe_b`, `rippe_dy` | rib width and offset |
| `blende_b`, `blende_sd` | baffle width (50) and its screw clearance hole |
| `zapfen_b/l/h/r/sd/spiel` | peg width, length, height, edge radius, core hole, clearance |
| `kern_m2`, `kern_m4` | core-hole diameters for M2 and M4 |
| `trichter_d`, `trichter_t` | funnel diameter and depth at the peg's core hole |
| `kanten_r`, `kehle_r` | edge radius and inner fillet radius |
| `schraub_lk`, `schraub_d` | fan screw hole pattern (105) and hole diameter (6) |
| `schutz_*`, `strebe_*` | guard: wall, skirt, undersize, distance; strut width, pitch, radius, thickness |
| `druckbett`, `bett_rest` | print bed size (230) and what is left of it |
| `plattendicke`, `backentiefe`, `backendicke`, `maulweite`, `blechdicke`, `spiel`, `probelaenge` | fit-test frame: plate, jaw depth and thickness, jaw opening, sheet thickness, clearance, length |

## Regenerating

The scripts in `../scripts/` run inside FreeCAD (View → Panels → Python console), with the
document already open from `fan-mount/cad/`. They write the STL (and, where relevant, the FCStd) next
to the opened document; set the environment variable `FAN_MOUNT_CAD` to write somewhere else.

```python
ZIEL = "RadiatorFanLarge"            # name of the open document
exec(open("<repo>/fan-mount/scripts/build_variante.py").read())   # mount + pegs -> <ZIEL>.stl
exec(open("<repo>/fan-mount/scripts/build_schutz.py").read())     # finger guard -> RadiatorFanGuard.stl
exec(open("<repo>/fan-mount/scripts/build_zapfen.py").read())     # pegs on their own -> ZapfenLarge.stl
```

`passprobe.py` builds the test frames (and the first mount, `halter_A`). To change a dimension,
edit the sheet geometry in `radiator_sheets.csv` **and** in the `Masse` spreadsheet, then run the
script. The depth is a *derived* value (sum of the partial lengths) — if it differs from the
measurement, column E of the spreadsheet shows the difference instead of silently distributing it.

## Fit-test frames (Passproben)

Not a functional part. One print answers four questions:

1. Is the measured depth right?
2. Does the **edge grip** engage over the sheet edge, or does the grid end in a bead / a side panel
   where there is no free edge?
3. Is the **jaw opening** right — does it jam, or wobble?
4. How much does shrinkage distort the width over 141 mm (part C)?

Cross-section, across the wall:

```text
        ┌───────────────────────────────┐   base plate 3 mm
        │                               │
        █ ▁▁                       ▁▁ █     jaw 1.4 mm = sheet 1.0 + clearance 0.4
        █ ██                       ██ █     nose 1.5 mm grips under the sheet
        └──┘                       └──┘     jaw 2.5 mm, outside
          ↑                         ↑
          └──── sheet depth (65/101/136) ────┘
```

The part is **slid onto the sheet edge from the front**. The middle under the sheet is free — it
only clamps at the two edges.

Assumptions to check when you hold it against the radiator:

| Assumption | Value | If wrong |
|---|---|---|
| Sheet thickness | 1.0 mm | change `blechdicke` in the spreadsheet |
| Free sheet edge present | yes | edge grip fails → peg principle needed |
| Jaw depth sufficient | 6 mm | change `backentiefe` |

Print flat (base plate on the bed, noses up) in PLA, 0.2 mm layers, 3 perimeters — then no support
reaches into the jaw. About 60 cm³, a good 3 hours.

The edge grip was later **dropped** from the mounts (it made the part hard to print); the pegs
described below take over the fixing.

## The mount, first design ("Halter A")

`halter_A.stl` — clamp and **collar** (fan seat) in one part, for a 25 mm fan. The fan drops in and
rests on four 2 mm corner rests; there is **no floor** under it, it blows straight onto the sheet. A
base plate with a passage would be a throttle point right at the pressure side — exactly where an axial
fan is most sensitive.

### Ribs instead of a floor

Collar and clamp are joined by **two ribs** that sit on the unperforated edge strips (13 mm at A). A
continuous web across the full sheet depth covered **64 % of the fan outlet** in the first version —
precisely the part above the perforated field, i.e. the only one that does anything. With ribs it is
25 %, all of it collar wall and rests at the edge; **above the perforated field it is 100 % open**.

The script check "field open" tests this at 99 points. It was missing at first, which is why the
floor was only noticed in the picture.

### Asymmetric seat

A 120 mm fan on a 65 mm deep sheet overhangs by 55 mm. With only ~25 mm of wall distance it has to
move forward:

| | mm |
|---|---|
| Total overhang | 55 |
| of which backwards (wall side) | 14 |
| of which forwards (into the room) | 41 |
| Air gap to the wall | 8 |

`a_hinten = z_ecke` — the rear overhang is coupled to the corner length of the rests. As a result
`rippe_dy = 0` and **both ribs lie completely on the unperforated edge strips** of the sheet, while the
front rest continues seamlessly into rib 1.

The wall distance is therefore no longer the governing quantity but a check value:
`wandluft_ist = wandabstand − a_hinten − z_dicke` = 8 mm, requirement at least 5 mm. If the mount is
derived for a radiator with less wall distance, this is the cell where it shows.

### Height

Rest 2 mm + fan 25 mm = 27 mm. With ~55 mm of clear space in the office, **28 mm of intake space**
remain — just under the ~30 mm a 120 mm fan likes, but usable. If it gets too loud, 15 mm slim fans are
the lever; change `luefterhoehe` in the spreadsheet and regenerate.

### Print orientation

`halter_A.stl` is printed **flat, without turning and without special flags** — the part ends at z=0
and every face is supported from below.

**Material: white PETG.** PETG rather than PLA because PLA softens at about 60 °C and the mount sits on a
radiator. White matches the colour of the radiators.

Slicer settings used: 0.2 mm layers, max. speed 60, PETG at 265 °C nozzle / 75 °C bed. 140 layers,
3 h 28 min, 65 g — mount and all six pegs together.

### Collar height and sight screen

`zarge_innen` = 26 mm measured **from the fan rest**, i.e. `z_hoehe` = 28 mm from the sheet. The top
edge of the fan is at 2 + 25 = 27 mm — the black fan disappears completely behind the collar, with 1 mm
to spare.

With `kanten_r` = 1.5 mm the following edges are broken: all vertical outer edges, the upper
circumferential edge of the collar and the **three free top edges of each baffle** (two long sides, one
end).

The fourth baffle edge — the transition to the collar — gets a **fillet** (`kehle_r` = 1.5 mm) instead.
That is an *inner edge*: the rounding runs the other way than on the outer edges and **adds material**
instead of removing it. It stiffens the 2 mm thin baffle exactly where it hangs on the 28 mm high collar
wall. The fillet has to be applied **after** the outer edges: otherwise the lengthwise roundings of the
baffle run through to the transition and eat it away.

The price is intake space. For a 120 mm fan ~30 mm would be ideal:

| | Clear height | above the collar |
|---|---|---|
| A — office | ~55 mm | 27 mm |
| B — living room | 100 mm | 72 mm |
| C — dining room | 50 mm | **22 mm** |

In the dining room it gets tight — the fan is louder there and delivers less. If that bothers,
`zarge_innen` is the adjusting screw.

### Screwing the fan

Four holes **⌀6 mm** in the rest corners, hole spacing **105 × 105 mm** — the standard dimension for 120 mm
fans (hole centre 7.5 mm from every fan edge).

The reference is the fan corner, not the rest: if `z_spiel` or the fan position change, the holes move
along correctly. For other fan sizes `schraub_lk` is the adjusting screw (92 mm for a 92 mm fan, 71.5 mm
for an 80 mm one).

**3.2 mm** remain between the hole edge and the edge of the rest. That is thin — fan screws are normally
M4, for which a 4.5 mm hole would do and leave a 4.0 mm web. At ⌀6 an M4 screw has play; with a washer or
a nut from below that is no problem, for a self-tapping screw directly into PLA 3.5 mm would be right.

### Baffle against short-circuit flow

On the left and right, **50 mm of floor area** each attach (`blende_b`). They cover the neighbouring slots
so the air does not short-circuit back up through them instead of going down through the convector
fins.

The baffle only extends over the sheet depth (y = 0…65), not over the full collar depth — otherwise 62 mm
would hang free in the air. Thickness as the rests, 2 mm.

That makes the part **226.6 mm wide** on a 230 mm usable bed: only 3.4 mm to spare. The cell `bett_rest`
in the spreadsheet accounts for this, and the check "fits the bed" fails before a part that is too wide
reaches the slicer. For radiators B and C, which have wider sheets, the baffle has to be printed in
segments and joined.

### Fixing — pegs (Zapfen; 6× in the complete STL: 2× each M2, M3, M4)

A **solid** block with rounded edges that engages a radiator slot with a **positive fit**. Outer size
7.4 × 39 mm — slot width minus 0.2 mm clearance times the full width of the perforated field. It can
neither turn nor wander.

| | mm |
|---|---|
| Outer | 7.4 × 39.0 |
| Height | 7.0 |
| Edge radius (4 vertical edges) | 2.0 |
| Core hole, self-tapping, through | ⌀1.6 (M2) / 2.5 (M3) / 3.3 (M4) |

**Two pegs per screw size** are printed, because it is only at assembly that it becomes clear which
screws are at hand. Two are installed, the rest is spare. Order on the bed from left to right: M2, M2,
M3, M3, M4, M4. The web next to the hole stays 2.05 mm thick even with M4.

The peg is pushed through the slot from below and screwed into its core hole with **one M3 through the
baffle**.

The two diameters belong together and must not be equal:

| | ⌀ | Function |
|---|---|---|
| Baffle (`blende_sd`) | 3.4 mm | clearance hole — the screw runs through freely |
| Peg (`zapfen_sd`) | 2.5 mm | core hole — the screw cuts its thread |

If the baffle hole were as tight, the screw would cut there too and would not pull the two parts
together.

The core hole goes **through the whole peg**: if the cut thread gives way on one side, the peg is turned
over and the other side is used.

The matching hole in each baffle is centred on the radiator depth (y = 32.5) and in the baffle — the two
line up.

**Assembly vs. printing:** the pegs are mounted under the baffles. For printing they lie loose in the fan
opening in `halter_A_komplett.stl`, where the mount is empty anyway — an STL may contain several separate
solids; the slicer treats them as objects of their own.

The original edge grip (jaws and noses below z=0) was removed: it made the part hard to print, and the
fixing is now done by these two parts.

**To check at the first fitting:** whether 7.4 mm really goes into the slot. Printed outer dimensions in
PLA tend to come out 0.1–0.2 mm too large; `zapfen_spiel` in the spreadsheet is the adjusting screw.

*(The numbers above are those of the first design. The current spreadsheets differ: peg width
`zapfen_b` = slot width − 0.2 mm = 7.4 / 7.5 / 7.8 mm for A / B / C, peg length = width of the perforated
field (39 / 75 / 38.5 mm), core hole `zapfen_sd` = 2.0 mm, baffle hole `blende_sd` = 3.0 mm, funnels of
⌀2.5 mm × 1.2 mm at both ends of the core hole. The principle — core hole smaller than the baffle hole —
is the same.)*

### Possible side effect

The fan touches the sheet through the corner rests and transmits vibration into a large thin sheet. If it
hums: increase `z_auflage` and put a strip of foam rubber underneath.

---

## Printability

Checked on the turned print orientation (`halter_A_gedreht.stl`, a file that is no longer in the
repository). What matters is not the **area** of an overhang but its **span** — and whether it starts free
in the air or bridges between two walls.

| Place | z | Span | Kind |
|---|---|---|---|
| Ribs (2×) | 10.0 mm | **12 mm** | bridge between the collar walls |
| Fan rests (4×) | 10.0 mm | **14 mm** | hang on the collar wall |
| Clamp noses (2×) | 13.4 mm | **2 mm** | bridge |

All below the 20 mm limit, all connected on both sides. **No support material needed**, no face starts
free in the air.

### Why one piece

A two-part variant (collar + slide-on clamps with a dovetail) was calculated and discarded again. The
reason is structural: the collar is 127 mm wide, the sheet only 65 mm. Every connection between the two
bridges 31 mm per side — the bridge does not disappear, it only moves. Separate parts brought **more**
overhang in total (4179 mm² against 2538 mm² for the one-piece part, at a larger span) and an additional
joint.

It stays one piece as long as the spans are below 20 mm. If the collar ever becomes much taller (a thicker
fan), the ribs are the place that becomes critical first.

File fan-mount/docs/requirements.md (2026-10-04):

# fan-mount — 3D printed fan mounts for radiator cooling assist: requirements

This is the original requirements and concept document (started 2026-08-15). It is kept
as written; what has actually been built since is summarised in the status table in the
[component README](../README.md#status), and the design details are in
[design-notes.md](design-notes.md). Where this document says "magnets", the built parts
use printed pegs in the radiator slots and screws instead (see design-notes.md).

## 1. Problem

Heat pump runs in cooling mode over the existing wet radiator circuit (panel
radiators). The heat pump's **minimum cooling capacity is larger than what the
radiators can dissipate into the rooms**, so the return water never warms up
enough. Result: the heat pump satisfies its target quickly, shuts off, and
short-cycles.

Root cause on the room side: panel radiators are mounted **low on the wall**.
That placement is optimal for *heating* — the radiator warms air, the warm air
rises, and the resulting chimney draft through the convector fins is
self-sustaining and drives room-scale mixing.

In *cooling* the same geometry works against us:

- Cooled air is **denser** and sinks. The radiator is already at the floor, so
  the buoyancy column is ~0 cm tall. There is essentially no driving head.
- Air-side heat transfer collapses to near-still-air free convection. The
  air side is by far the dominant thermal resistance, so the whole radiator
  capacity collapses with it.
- The cold air **puddles on the floor** around the radiator. The radiator then
  re-inhales its own cold exhaust (short-circuit), which kills the air-to-water
  temperature difference and therefore the capacity a second time.
- The room stratifies: cold at the floor, warm at the ceiling. Comfort is bad
  *and* the warm air that we actually want to cool never reaches the radiator.

Rule of thumb: a panel radiator in cooling delivers roughly **10–15 % of its
nominal heating output**. Forced air over the fins typically recovers a factor
of **3–4×** of that, because it attacks the dominant resistance directly.

## 2. Goals

G1. **Raise cooling capacity per radiator** enough that the heat pump can run
    continuously at its minimum modulation instead of short-cycling.
    Mechanism: forced convection over the convector fins (air-side `h` up).

G2. **Feed the radiator the warmest air available in the room** — maximise the
    air-to-water temperature difference, and avoid re-inhaling the cold puddle.

G3. **Destratify the room**: drive a room-scale circulation loop so the warm
    ceiling air is continuously brought back down to the radiator. This serves
    G1 and G2 (warmer intake air) *and* comfort (uniform room temperature) at
    the same time — they are the same objective seen from two ends.

G4. **Quiet.** These run continuously in living rooms. Target: inaudible at
    2 m, i.e. fans undervolted / PWM-limited, no resonance transmitted into the
    radiator sheet metal.

G5. **Non-destructive, reversible mounting.** No drilling, no adhesive, no
    modification of the radiator. The parts stay on year-round (C4), but must
    still come off by hand for cleaning inside the radiator, and must leave the
    radiator's heating performance intact in winter (C5).

## 3. Airflow decision — where does the fan go, and which way?

**Decision: fans sit on TOP of the radiator and blow DOWNWARD through the
convector channel. Discharge at the bottom is turned horizontally into the room
by a deflector.**

### Rationale

Buoyancy inside the radiator channel is irrelevant once a fan is involved.
Over a 0.6 m panel at ΔT = 5 K the buoyant head is
`Δp = ρ·g·h·ΔT/T ≈ 1.2 · 9.81 · 0.6 · 5/295 ≈ 0.12 Pa`,
against 20–50 Pa of fan static pressure. So "fighting gravity" is a non-issue
in either direction, and the decision is made purely on **intake air
temperature** and **room air pattern**.

| | Top intake, blow down (chosen) | Bottom intake, blow up |
|---|---|---|
| Intake air | Warmest air in the room reaches the radiator top | Coldest air — the floor puddle |
| Short-circuit risk | Low: intake and exhaust are maximally separated along the stratification axis | High: exhaust cools, sinks, is re-inhaled |
| Window interaction | Intercepts the warm downdraught/updraught at the glass — cools the heat gain at its source | Ignores it |
| Room loop | Floor jet → across room → up at far wall → back along ceiling → into the top intake. Closed, self-reinforcing loop. | Cold plume thrown up, mixes at ceiling, then falls back to intake — also mixes, but starves its own intake |
| Comfort risk | Cold draught at ankle level | Cold air thrown at seated head height |

The chosen direction wins on G2 decisively, and its room loop (G3) has the
useful property that the **return leg of the loop terminates at the fan
intake** — the warm ceiling air is actively pulled down and consumed, rather
than left to find its own way.

The ankle-draught risk is the one real drawback and is handled by the discharge
deflector: aim the jet horizontally out into the room rather than straight down
at the floor, and keep the discharge velocity moderate. Note also that the water
in this system is deliberately *not* very cold (see C1), so the jet is cool, not
icy.

### Consequences for the parts

- The top opening of the radiator must be **sealed except at the fans**,
  otherwise most of the air spills back out of the top slot instead of going
  down the channel. Blanking plates are as important as the fan mounts.
- Fan spacing must give reasonably even coverage over the radiator length —
  target roughly **one 120 mm fan per 250–300 mm of radiator length**.

## 4. Sizing estimate (to be checked against the real radiator)

For a target of ~700 W per radiator:

```
V̇ = Q / (ρ · cp · ΔT_air)
   = 700 W / (1.2 kg/m³ · 1005 J/kgK · 8 K) · 3600
   ≈ 260 m³/h
```

At an *installed* (not free-air) delivery of ~50–60 m³/h per 120 mm fan through
the fin pack, that is **4–5 fans** per radiator. Numbers are estimates and need
to be validated by measurement (see §8).

Implication for fan selection: the fins are a real pressure drop, so pick
**static-pressure** fans (e.g. Arctic P12, Noctua NF-F12 class), not
high-airflow/low-pressure case fans. Power is negligible: ~1.5 W per fan
undervolted, ~6–8 W per radiator, versus several hundred W of recovered
capacity.

## 5. Constraints

C1. **Condensation — already handled by the heat pump control.** The heat pump
    reads room temperature and humidity and raises the coolant temperature to
    keep the surfaces above dew point, so dripping is designed out at system
    level. Nothing in this project may defeat that.
    Two residual notes, not open risks:
    - Forcing air over the fins does not meaningfully lower the fin surface
      temperature (the water-side resistance is small either way, so the metal
      sits near water temperature regardless). The existing control input is
      therefore still the right one after fans are added.
    - What fans *do* change is the deposition rate if the margin is ever thin,
      and the coldest spot is the flow-inlet end of the radiator. Worth one
      look at the actual dew point margin under fan operation (§8) — if the
      control already holds a couple of K, there is nothing to do.

C2. No modification of the radiator (G5). Mounting is by magnets onto the steel
    panels (§6), backed up by hooking over the existing top slot and bottom
    edge where a magnet alone cannot locate the part precisely enough.

C3. Radiators sit under windows in most rooms — a windowsill limits the
    vertical space available above the radiator. The top mount must stay low
    profile. Available headroom is a key dimension (see §8).

C4. **Parts stay mounted year-round** (decided). They therefore see radiator
    surface temperatures in the heating season, where PLA creeps and softens
    (~55–60 °C). → Print in **PETG or ASA**. The hook and clamp geometry needs
    extra clearance for thermal expansion, and must not rely on a press-fit
    that would relax when warm.

C5. **Heating-season bypass.** Because the parts stay on year-round (C4), the
    blanking tiles (P2) that seal the top slot against fan bypass would also
    block the natural convection chimney in winter, when it is exactly what
    makes the radiator work. Must be resolved by one of:
    1. tiles separately removable from the fan mounts (seasonal chore);
    2. tiles as gravity/pressure flaps — pressed shut by downward fan flow,
       falling open when the fans stop (self-managing, more parts);
    3. **turn the fans over in winter** so they blow *upward*, assisting the
       chimney instead of blocking it. Raises heating output, which permits a
       lower flow temperature and a better COP — turns the project into a
       year-round gain.
    → Preferred: 3, with 1 as fallback. Consequence for the design: the duct
    geometry must not be so optimised for downflow that it chokes upflow.

    **Not by reversing polarity.** PC fans are brushless DC motors: the driver
    IC and Hall sensor sit inside the hub, and the direction of rotation comes
    from the order in which that IC energises the coils — not from the supply
    polarity. Swapping +12 V and GND does not reverse the fan, it reverse-feeds
    a driver IC that usually has no protection. The blades are aerofoils with a
    defined leading edge and the frame has an inlet radius on one side and the
    struts on the other, so even a genuinely reversed impeller would move far
    less air.

    **Physically turning the fan over is what works**, and the existing mount
    already allows it: the surround is a 120.6 mm square open at the top, and
    the M4 hole pattern sits at `(120 − 105) / 2 = 7.5 mm` from every edge —
    point-symmetric, so the fan drops onto the same pegs either way up. The
    seasonal chore is lifting it out, flipping it, putting it back.

C6. Fans are standard 120 × 120 × 25 mm with the standard 105 mm mounting hole
    pattern, M4/self-tapping screws or press-fit pins.

C7. Cabling: fans daisy-chained per radiator to a single 12 V supply.
    Ideally switched from the heat pump's cooling signal so they only run when
    cooling is active.

## 6. Material strategy — print only what must be printed

Printing is the right tool for **interfaces**: things that must match the
radiator's exact profile, hold a fan at an exact position, or clip onto an
edge. It is the wrong tool for **large flat areas and long shallow curves** —
those print slowly, warp in PETG, eat filament, and a sheet of stock material
does the job better and cheaper.

So the rule for this project: *printed clips and brackets carrying cut sheet
stock.* Standard materials to use:

| Material | Where | Why |
|---|---|---|
| **Neodymium magnets** (10×3 mm discs, in printed pockets) | mounting P1/P2/P3 to the radiator | The radiator is painted steel. Magnets give a strong, zero-force, non-destructive, instantly removable mount — this satisfies G5 and C2 almost for free, and removes most of the clamping geometry from the design. Face them with felt or foam tape so they cannot scratch the paint, and keep them off the hottest zones (N-grade magnets lose strength above ~80 °C; radiator surface stays well below that, but use N42SH or similar if in doubt). |
| **PVC foam board** (Forex/Kapa, 3–5 mm) or thin aluminium sheet | blanking tiles P2, deflector P3 body | Cuts with a knife, stiff, flat, cheap, bends to a curve (aluminium) or scores and snaps (PVC). Replaces the largest printed areas entirely. |
| **Self-adhesive foam weatherstrip** (EPDM, D- or P-profile) | every printed-part-to-metal contact | Does three jobs at once: seals the shroud so air cannot bypass, takes up manufacturing tolerance between the print and the real radiator, and decouples fan vibration from the radiator sheet metal — which is the main noise path (G4). Cheap and it makes the printed parts far less dimension-critical. |
| **Silicone fan mounting pins** (standard PC part) | fan → bracket | Vibration isolation at the source, and no screws. Directly serves G4. |
| **Aluminium tape** | sealing seams between tiles | Faster than designing overlapping joints. |
| **Fan grills / finger guards** (standard 120 mm wire guards) | intake side | Safety, off the shelf, no reason to print one. |
| **12 V PSU, PWM controller, fan splitters/hub** | electrics | All standard PC parts. |

Consequence: the printed parts get *smaller and more numerous* — end caps,
edge clips, magnet carriers, fan shrouds — rather than a few big shells. That
is also what prints reliably in PETG.

## 7. Parts to design (draft list)

| # | Part | Printed portion | Stock portion |
|---|---|---|---|
| P1 | **Fan hanger / top mount** — holds one 120 mm fan over the convector channel, sealed to the top slot | bracket, fan seat with silicone-pin holes, magnet pockets, duct collar down into the slot | foam weatherstrip seal, silicone pins, wire guard |
| P2 | **Blanking tile** — closes the top slot between the fans so air cannot bypass (§3), must not defeat winter chimney (C5) | end clips / magnet carriers only | PVC foam or aluminium sheet cut to length |
| P3 | **Discharge deflector** — turns the downward flow into a horizontal jet into the room; sets the room loop (G3), defuses the ankle draught | end caps and intermediate edge clips that hold the sheet at the right angle | bent aluminium or PVC foam sheet |
| P4 | **Cable clip / daisy-chain holder** | all of it, trivial | — |

Design order: P1 first (it fixes all interface dimensions), then P2 (shares
the magnet/clip geometry with P1), then P3, then P4.

All dimensions driven from a **FreeCAD spreadsheet** so the same model
re-generates for the different radiator types in the house (several types
confirmed — see measurements.md).

## 8. Open questions / to measure

Needed before P1 can be modelled — see measurements.md:

- Radiator type (11 / 21 / 22 / 33) and manufacturer
- Height, length, depth (front face to wall face)
- Width of the **top slot** and its internal clear gap between the fin packs
- Is the top grille removable? Are the side covers removable?
- Clear headroom above the radiator to the windowsill
- Floor clearance under the radiator, and wall standoff
- Number of radiators to equip, and their sizes

To validate afterwards:

- Return water temperature rise, before vs. after (the actual success metric —
  it is what stops the short-cycling)
- Heat pump runtime / cycles per hour, before vs. after
- Room temperature at floor vs. ceiling, before vs. after (destratification, G3)
- Room humidity and dew point margin (C1)

## 9. Note on scope

Fans on the radiators raise the emitter capacity, which is the correct lever for
"minimum cooling output exceeds the emitter capacity". The alternative levers —
a buffer volume to absorb the excess, or raising the flow temperature — are
system-side and out of scope here, but worth keeping in mind if the fans alone
do not close the gap.

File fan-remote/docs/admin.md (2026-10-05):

# fan-remote — administration

## Build and flash

Needs PlatformIO (`pio`). The first build creates `config.ini` from `config.ini.template`
and prints a **random admin password** once; edit the file (mode 600, gitignored) for the
service aliases (`mqtt`, `syslog`), the HA prefix, standby timing and so on. That one password
is the settings login, the setup access point password and the OTA password of every board
flashed from this tree - on purpose (home network), so keep `config.ini` safe.

```sh
pio run -e xiao_c3 -t upload                  # new board, USB-C
pio run -e ota -t upload --upload-port fan-control-1   # update over WiFi (XIAO C6: -e ota_c6)
```

A XIAO ESP32-C6 works too (same pin positions): `-e xiao_c6` / `-e ota_c6`.

`min_spiffs.csv` gives two 1.9 MB app slots (OTA); the firmware is about 1.2 MB.
Never run two `pio` invocations at once. Updating over WiFi reboots the board: the
PWM pins float for a moment and the fans can burst to full speed (see spec.md).

## Adding a board

Boards are numbered in `devices.csv` (MAC → number, committed). The number is the host name
(`fan-control-N`), the MQTT topics (`fan-control/fan-control-N/…`), the setup AP (`fan-control-N-setup`) and the Home
Assistant ids. Numbers are never reused.

1. Plug the board in and register it: `python3 scripts/register_device.py --port /dev/ttyACM0`
   (prints `fan-control-N`; `devices.csv` gains a line, commit it). Or give the MAC:
   `register_device.py 58:e6:c5:19:38:60 "kitchen"`.
2. Flash over USB-C (`pio run -e xiao_c3 -t upload`, `-e xiao_c6` for a C6). The table is
   compiled in, so build after registering.
3. The board opens the access point `fan-control-N-setup` (password: `admin_password` from `config.ini`). Join it from a
   phone; the page asks for WiFi, a friendly name and the broker alias.
4. The board appears in HA within seconds (broker + MQTT integration + discovery on).
5. Open the page → settings → fans: set names, *Min* duty and which channels exist.

A board that is not in the table still works, as `fan-control-new-xxxxxx` (last three MAC bytes):
register it and reflash to get its number. The number never changes; renaming only changes
the friendly name. Replacing a board therefore creates a new HA device. **Renumbering a
board** (or first moving one from MAC ids): publish an empty retained message to its old
`homeassistant/+/<oldid>_*/config` topics before flashing, so HA drops the old entities
and the new ones keep the entity ids, then clear the old `fan-control/<oldid>/#` retained topics.

## Status LED

Settings → Status LED (or `led` in `/api/config`). Build defaults are `led_mode`, `led_day`, `led_night`,
`night_from`, `night_to` in `config.ini`. To test the problem signal on a board whose fan is off, unplug a
running fan (stalled after about 8 s) or enter a wrong broker under Network and reboot; `curl
http://fan-control-1/api/netstatus` shows `health.issues`. A different board with its own LED pins: set
`LED_FAN_PIN` / `LED_ALERT_PIN` / `LED_ACTIVE_LOW` in the environment's `build_flags`.

## Runtime configuration

Compile-time values are only defaults. Per board, behind the admin login:

```sh
curl -u admin:<pw> -X POST http://fan-control-1/api/netconfig \
     -d mqttHost=mqtt -d syslogHost=syslog -d ntpHost=de.pool.ntp.org
curl -u admin:<pw> -X POST http://fan-control-1/api/netconfig -d defaults=1   # back to config.ini
curl http://fan-control-1/api/netstatus     # firmware, version, WiFi, each resource and its last result
```

Stored in NVS (a firmware update keeps it), applied at the next boot. The broker name
is resolved on every connect, so a moved alias is followed without a reboot; the
syslog name is re-resolved hourly and after a failed send.

## Operations

* **Logs**: serial (USB, 115200) and UDP syslog to the alias `syslog`
  (`app-name fan-remote`, host = device id). Stall/recovery and config changes are logged.
* **Forgetting WiFi**: settings → *Forget WiFi*, or `POST /api/wifireset`. The board
  reboots into the setup portal.
* **Updating over WiFi:** `pio run -e ota -t upload --upload-port fan-control-N`
  (`ota_c6` for a C6) pushes the image to the board's own web server (`POST /api/update`,
  admin login). The host only makes an outbound connection, so **no firewall port is needed**.
  The script refuses unless `VERSION` is committed and higher than what the board runs, so
  bump it (patch for fixes, minor for features) in the commit that changes behaviour, before
  flashing; `FAN_SKIP_VERSION_CHECK=1` overrides for throwaway builds.
  The script retries on a flaky link; a board that was flashed with an older firmware without
  `/api/update` answers 404 and needs one USB or ArduinoOTA flash first. A wrong chip image is
  rejected at the end of the upload and leaves the running firmware alone. By hand:
  `curl -u admin:<pw> -F firmware=@.pio/build/xiao_c6/firmware.bin http://fan-control-1/api/update`.
* **ArduinoOTA fallback** (`-e espota` / `espota_c6`): the board connects back to the host, so a
  host firewall must let that through: pin the port with `FAN_OTA_HOST_PORT=3333` and open it
  (`sudo firewall-cmd --add-port=3333/tcp`, runtime only). `FAN_OTA_PASSWORD=…` overrides the
  password for a board whose own differs. A weak WiFi link can break these uploads ("Broken
  pipe", "No response").
* **Factory reset**: `pio run -e xiao_c3 -t erase`, then flash again.
* **Backup**: nothing on the board needs a backup; `config.ini` (secrets) belongs in the
  password manager, everything else is the repository. Per-board settings are
  re-enterable in a minute.

## Restore procedure

1. Clone the repository; install PlatformIO.
2. Restore `config.ini` from the password manager (or let the build create a new one;
   then boards keep their stored password until you change it in the portal).
3. `pio run -e xiao_c3 -t upload` for each board, then the portal steps above.
4. Verify: `curl http://<board>/api/netstatus` shows MQTT `connected`; HA shows the device.

## Troubleshooting

| Symptom | Check |
|---|---|
| Fan does not start, card says Stalled | Tach wired? `tach` off in settings if the fan has no tach wire. Fan stuck? *Min*/start duty too low for this fan? Try a higher *Min* |
| RPM reads double/half | *Pulses per revolution* (PC fans: 2; some server fans 4) |
| RPM jumps around at low speed | Raise *Min*; a fan at the edge of stalling gives uneven pulses |
| Page loads, no live updates | A proxy buffering `text/event-stream`; the page falls back to polling every 3 s |
| Board not in HA | `/api/netstatus` MQTT line; broker credentials in settings; discovery prefix `homeassistant` |
| Settings prompt keeps coming back | Wrong password. After 5 failures the login is locked for 30 s |
| Fans burst briefly at reset | Hardware: no pull-down on the PWM lines (spec.md). Avoid needless reboots |

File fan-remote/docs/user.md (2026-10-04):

# fan-remote — user guide

## The web page

Open `http://fan-control-N/` (the board announces this name in its DHCP request, so a router or DNS server that registers DHCP hostnames resolves it - the firmware does not use mDNS; N is the number from `devices.csv`; also on the serial output and in the
router's device list) or the board's IP. Works on phones and desktops, light and
dark, German or English following the browser language.

Every enabled fan has a card:

| Element | Meaning |
|---|---|
| Spinning fan icon | Turns with the measured RPM; grey = off, red = stalled |
| Big number | RPM from the tach line (`–` if the fan has no tach) |
| Round power button | Off, or back to the last non-zero speed |
| Slider | Speed 0…100. `0` is off, `1` is the quietest speed that really runs, `100` the maximum |
| `PWM n %` | The duty actually sent to the fan right now (it follows the slider smoothly) |
| Chips | Preset speeds: Quiet, Low, Medium, High, Max. The matching one is lit |

The **All fans** card at the top sets every enabled fan at once.

### Colour and status LED

Every controller has its **own base colour** (from its number), so you can tell several of them apart; red and
green always keep their meaning (problem / ok).

Where the module has a LED (XIAO ESP32-C6: the yellow one) it shows the state: **steady = fans on**,
**a short flash once a second = a problem, fans off**, **blinking = fans on and a problem**, dark = fans off and
everything fine. Problems are: a fan stalled, no WiFi, no MQTT broker (when one is set), clock not synchronised.
The brightness is lower at night; Settings → Status LED sets day and night brightness, the night hours, or
switches the LED off completely (dark operation). Settings → Status shows the current health.

### Standby

After a minute without any interaction the controller saves power (WiFi modem sleep, lower
CPU clock); the fans are not affected. The first touch after a pause wakes it: the page
shows the usual pending marker for a fraction of a second longer. Settings → Status shows
the current mode.

### Soft start

Switching a fan on never jumps to a high speed. The duty rises slowly until the fan
turns, then settles at the target. Do not be surprised that "Starting" lasts a
second or two at low speeds: that is how it stays quiet. If a fan does not turn up
to 50 % duty for three seconds, it is switched off and flagged **Stalled**; the
board retries after 15 s, then 30 s, up to every 5 min. Moving the slider to 0
acknowledges the fault.

### Settings (gear icon)

Asks for the admin login (user `admin`). Everything is stored on the board. Nothing is saved
automatically: a section with unsaved edits shows a dot in the dialog title, "Unsaved changes" next
to its **Save** button, and the button turns solid; changing a value back removes the marker, and
closing with unsaved edits asks first. **Save** covers name, fans, presets and behaviour (applies at
once), **Save network** the broker, syslog and NTP (applies after a reboot).

* **Fans**: name (empty = "Fan N" / "Lüfter N"), enabled, *Min* and *Max* duty, tach wired, pulses per revolution
  (PC fans: 2). Set *Min* to the lowest duty at which your fan still turns reliably
  (default 5 %; many PWM fans keep turning at that, some stall below 15–20 %, so raise it if a card turns "Stalled" at low speeds). *Max* caps the loudest setting.
* **Preset speeds**: the five chips, in speed units (not duty).
* **Behaviour**: how fast the duty may rise/fall, and what happens after power-up
  (restore last speeds, or all off).
* **Network**: broker, syslog, NTP. Applies after a reboot. The login is user `admin`; the password is `admin_password` from the build's `config.ini`.

## Home Assistant

With MQTT discovery enabled (default) every board appears as a device with one *fan*
per enabled channel (on/off, percentage, preset modes), a **Speed** slider (0–100 %, 1 % steps,
a plain number entity that shows up on the device page and in default dashboards), an *RPM* sensor, a *stalled*
problem sensor, plus WiFi signal and uptime. Entities appear within seconds of the
board connecting to the broker. A fan entity at `0 %` is off; HA's percentage is the
same 1…100 speed as the slider.

Renaming the board or a fan in the settings updates the names in Home Assistant at once. The
**entity ids** stay as they were when the entities were first created: Home Assistant remembers deleted
entities and gives a returning unique id its old entity id back (tested with HA 2026.9: removing
and re-announcing the discovery messages, as Zigbee2MQTT's `homeassistant_rename` does, restored
the old ids). To get new ids from the current names use Settings → Network → **Recreate Home
Assistant entities** (or `curl -u admin:… -d recreate=1 http://fan-control-1/api/discovery`):
the board removes its entities in Home Assistant, waits 2.5 s and announces them again under a new
generation number, so HA builds fresh entity ids. History and customisations of the old entities
are lost, so use it right after naming a new board, not later.

## MQTT

Topics are `fan-control/<id>/…`; the full list is in [spec.md](spec.md). Examples:

```sh
mosquitto_pub -h mqtt -t fan-control/fan-control-1/1/speed/set  -m 35        # fan 1 to speed 35
mosquitto_pub -h mqtt -t fan-control/fan-control-1/all/preset/set -m quiet   # everything quiet
mosquitto_pub -h mqtt -t fan-control/fan-control-1/2/power/set  -m OFF
mosquitto_sub -h mqtt -t 'fan-control/fan-control-1/#' -v
```

## HTTP

```sh
curl http://fan-control-1/api/state
curl -d ch=1 -d speed=40 http://fan-control-1/api/set
curl -d ch=all -d preset=quiet http://fan-control-1/api/set
curl http://fan-control-1/api/netstatus
```

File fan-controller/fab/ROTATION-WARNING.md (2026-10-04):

# Check part rotation in the fab's assembly preview

**Always go through the assembly preview before ordering.** In a first pass several parts showed up
rotated there, although our CPL is correct.

## Why

Not because of our files. The rotation values in `fan-controller-cpl.csv` match the board exactly —
checked part by part.

The cause is a known discrepancy between KiCad and JLCPCB: **they use different zero orientations for the
same packages.** It mainly affects SOT packages and polarised parts. The KiCad community maintains
correction tables for this (for example in the plugin `Bouni/kicad-jlcpcb-tools`) that add an offset on
export.

Those correction values are deliberately **not** built in here: they depend on the exact catalogue part
chosen, and a wrong value turns a part by 180°. For D1 and U2 that would make the board unusable.

## What to check

The preview shows every part at its position. The three polarised or asymmetric parts are the critical
ones — for the resistors the rotation is electrically irrelevant:

| Part | What to look for |
|---|---|
| **U2** AMS1117-5.0, SOT-223 | The wide tab must sit on the large pad. Pin 1 (GND) bottom left, pin 3 (VI) right. Rotated = regulator destroyed. |
| **D1** SS34, SMA | The cathode stripe must point to the marked side. The wrong way round, the diode blocks the supply. |
| **C2** 10 µF, 0805 | Ceramic, unpolarised — rotation not critical. |
| **F1** polyfuse, 1812 | Unpolarised — rotation not critical. |
| **R1–R12** 0603 | Not critical. |

In practice only **U2 and D1** are really dangerous. Both can be rotated individually in the preview.

## Why not correct automatically

We could hard-code an offset, but:

* the right value depends on the chosen catalogue part, not only on the package
* a wrong assumption only shows on the finished board
* the preview shows the result directly anyway

Correcting in the web interface is therefore the safer way — there you see immediately what happens.

## PCBWay

The same applies there. PCBWay usually reworks the assembly data manually and asks when something is
unclear, but you should not rely on that.

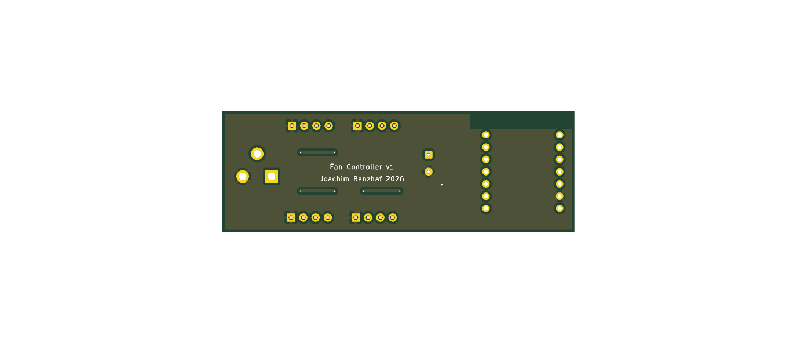
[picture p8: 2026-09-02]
fan-controller/docs/img/board-bottom.png

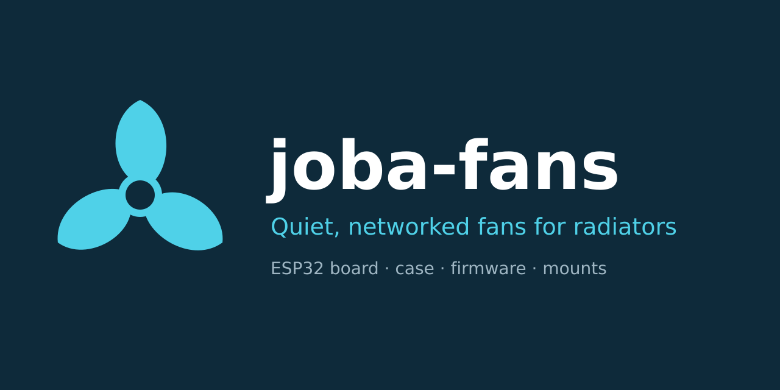
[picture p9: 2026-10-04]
assets/social-preview.png

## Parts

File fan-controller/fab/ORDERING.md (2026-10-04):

# Ordering options

Board: 72.9 × 25.0 mm, 2 layers. Target quantity at planning time: 20 (10 were finally ordered, see the
Outcome at the end).

Per board: **16 SMD parts** (12× 0603 resistors, 0805 cap, SMA diode, 1812
polyfuse, SOT-223 regulator) and **8 through-hole** (4 fan headers, 2 socket
headers, barrel jack, radial cap) — 24 placements, 68 solder joints.

U1 (the XIAO) is DNP everywhere: it is socketed and you supply it.

---

## Option A — assembled, ~€95 / ~€4.70 per board

Send `fan-controller-fab.zip` to JLCPCB (or PCBWay / Aisler) for a
20-off assembled run.

Estimated from JLCPCB's published rates — **verify at order time, these
move**:

| | USD |
|---|---|
| Setup | 8.00 |
| Stencil | 1.50 |
| SMT placement (660 joints) | 1.12 |
| Hand-solder THT (700 joints) | 15.61 |
| Bare PCBs | 15–25 |
| Components, 20 sets | 25–40 |
| Shipping to DE | 20–30 |
| **Total** | **~103 USD ≈ 95 EUR** |

The through-hole line dominates: JLCPCB charges a $3.50 hand-soldering fee
plus $0.0173 per joint, and this board has 35 THT joints each. That single
item is about half the labour cost. Reducing THT count is the main lever if
the quote comes back high.

**Effort: none.** Boards arrive ready; plug in the XIAO modules.

---

## Option B — bare PCBs panelised, ~€5 + shipping

Exploits the standard "5 boards ≤ 100×100 mm, dirt cheap" deal by putting
several circuits on one panel with cut lines between them.

**The arithmetic is tight.** Four boards stacked is 4 × 25.0 = exactly
100.0 mm with *zero* gap — most fabs will not accept that, and it leaves
nothing for panel rails. A 3-across-plus-1-on-top arrangement is
75 × 97.9 mm before gaps, which also exceeds 100 mm on one axis once
routing gaps are added.

The board cannot be made shorter without rerouting: the `+12V_PROT` traces
already sit at exactly 0.5 mm from both edges, the design-rule minimum, so
there is **zero slack** in the current layout. Bigger resistors would not
help — the height is set by trace routing, not part size.

**What does fit: 3-up.** 75 × 72.9 mm, comfortable gaps, no design changes.
A 5-panel order yields **15 boards**.

**Effort: substantial.** Hand-assembling 15–20 boards means ~240 0603
resistors, 15–20 each of SOT-223 regulator, SMA diode, 1812 polyfuse, plus
all the connectors. Several evenings.

Also: you own the panel's correctness. A mistake multiplies across every
copy, and some fabs charge a panelisation fee that eats the saving.

---

## Recommendation

Get a real quote for Option A before committing to B. The estimate above
puts assembled at ~€4.70/board — if that holds, the saving from Option B is
perhaps €60–70 in exchange for several evenings of soldering and the risk of
panelising it yourself.

If the quote comes back much higher than estimated, the fallback that keeps
Option A viable is reducing the through-hole count, since that is what
drives the labour cost.

---

## Before ordering either way

1. **Fill in MPN / Supplier in the BOM**, or let the assembler substitute
   from stock — everything except the barrel jack and the AMS1117 is a
   generic jellybean part.
2. **Source 20 XIAO ESP32-C3 modules** if you do not have enough.
3. Sanity-check the gerbers in an online viewer before paying.

---

## Decision (2026-08-26): Option A, fully assembled

Also priced a middle route — SMD assembled, you fit the through-hole parts
yourself — at roughly €68 total (~€3.39/board), saving ~€33 against full
assembly. But that €33 is only ~€15 of actual labour; the rest assumes you
source the THT components yourself instead of paying the assembler's markup.
Not worth 2–4 hours over 700 joints.

Fixed costs dominate at this quantity and put €50 out of reach regardless:
shipping (~€23) and bare PCBs (~€18) alone are €41 before any labour.

**Going with fully assembled**, subject to the real quote landing near the
~€95–100 estimate. If it comes back much higher, the lever is the
through-hole count — that is what drives the labour cost.

---

## Outcome

Ordered from **PCBWay**, turnkey, **10 units** (not the 20 planned above): €75.77 in total, €7.58 per board.
That is more than the ~€4.70 per board estimated for Option A. The breakdown and the problems met on the way
are in the [build log](../docs/build-log.html), stage 08.

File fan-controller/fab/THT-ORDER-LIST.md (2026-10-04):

# Through-hole parts — to be sourced yourself

**Only relevant for an order at JLCPCB.** Their catalogue does not carry these parts; they are removed from
the BOM and CPL there and soldered by hand.

**With PCBWay this list does not apply:** they assemble the through-hole parts too (through-hole
assembly), and `pcbway/` contains them in BOM and CPL, with sourcing details in the Note column. The
ordered run was assembled by PCBWay.

Quantities are given **per board** and for **10 boards** (the run that was ordered). Dimensions come from
the footprints on the board — please check them when buying, above all pitch and drill diameter.

---

## C1 — electrolytic capacitor 220 µF

| | |
|---|---|
| Quantity | 1 per board (10) |
| Capacitance | 220 µF |
| Voltage | **≥ 25 V** (the rail carries 12 V) |
| Package | radial leaded, upright |
| **Pitch** | **3.5 mm** |
| Drill | 0.8 mm |
| Max. diameter | 8 mm |
| Height | not critical, ~11 mm usual |

Search term: "electrolytic 220µF 25V radial 3.5mm pitch 8mm".

Note: JLCPCB had suggested an **SMD** type here (C2941234, 6.3 × 5.8 mm). It does not fit — the board has
leaded pads.

Mind the polarity: the positive terminal is marked on the silkscreen.

---

## J1 — DC barrel jack 5.5 × 2.1 mm

| | |
|---|---|
| Quantity | 1 per board (10) |
| Type | panel-mount jack, **horizontal / right-angle** |
| Centre pin | 2.1 mm |
| Outer diameter | 5.5 mm |
| Terminals | 3 pins (plus, minus, switch/mechanical) |
| Drills | 1.6 mm |
| Pin spacing | 3.0 mm (x), 4.7 mm (y) |
| Current | ≥ 2 A |

Reference type: **CUI PJ-102AH** — the footprint comes from this part. The widely available "DC-005"
jacks with the same pin pattern are compatible; compare the dimension drawing.

The jack overhangs the board edge — intended, so that the plug can be reached from outside (see
[`fan-housing`](../../fan-housing/)).

---

## J2–J5 — fan pin headers 1×4

| | |
|---|---|
| Quantity | 4 per board (**40**) |
| Type | pin header, straight, upright |
| Positions | 1×4 |
| **Pitch** | **2.54 mm** |
| Drill | 1.0 mm |
| Pin length | ≥ 6 mm (usual standard) |

Cheapest as a **40-pin strip to be cut** — 4 strips are enough for 10 boards. Search term: "pin header
1x40 2.54mm straight".

These four connectors take the PC fans (GND, +12 V, tach, PWM). They are **unshrouded** headers without
polarisation — see the warning in the [component README](../README.md#known-issues).

---

## U1 — female headers for the XIAO module

| | |
|---|---|
| Quantity | 2 per board (**20**) |
| Type | female header, straight, upright |
| Positions | 1×7 |
| **Pitch** | **2.54 mm** |
| Drill | 0.89 mm |
| Row spacing | 15.24 mm (0.6") |

Also sensible as a 40-pin strip to be cut — one strip gives 5 pieces of 1×7 (with 5 contacts left over), so
20 pieces need 4 strips; plan **5**. Search term: "female header 1x40 2.54mm straight".

The XIAO module is plugged in here, not soldered in. A contact is usually lost when cutting, hence the
extra strip.

---

## Also to be sourced yourself

**1 Seeed XIAO ESP32-C3 per board.** Not part of the assembly; it is plugged in after the sockets are
soldered. (The XIAO ESP32-C6 is pin-compatible and also works with the firmware.)

---

## Overview

| Pos | Part | Per board | For 10 boards |
|---|---|---|---|
| C1 | electrolytic 220 µF/25 V, 3.5 mm pitch | 1 | 12 |
| J1 | DC jack 5.5×2.1 horizontal | 1 | 12 |
| J2–J5 | pin header 2.54 mm | 4 | 4× 1×40 |
| U1 | female header 2.54 mm | 2 | 5× 1×40 |
| — | XIAO ESP32-C3 | 1 | 10 |

Reichelt, Mouser or AliExpress carry everything; the strips are much cheaper there than pre-cut pieces.

---

## Soldering notes

**35 solder joints per board** in total, all uncritical — 2.54 mm pitch and a barrel jack, no fine pitch:

| Part | Joints |
|---|---|
| C1 | 2 |
| J1 | 3 |
| J2–J5 | 16 |
| U1 sockets | 14 |

Order: first the flat female headers (U1), then the pin headers, last the electrolytic cap and the jack.
Align the sockets with the module plugged in while soldering, so that they line up.

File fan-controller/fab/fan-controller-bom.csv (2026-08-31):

Comment | Designator | Footprint | LCSC Part #
10uF | C2 | Capacitor_SMD:C_0805_2012Metric | C440198
SS34 | D1 | Diode_SMD:D_SMA | C8678
1.5A | F1 | Fuse:Fuse_1812_4532Metric | C209713
10k | R1,R2,R3,R4 | Resistor_SMD:R_0603_1608Metric | C25804
1k | R5,R6,R7,R8 | Resistor_SMD:R_0603_1608Metric | C21190
330 | R9,R10,R11,R12 | Resistor_SMD:R_0603_1608Metric | C23138
AMS1117-5.0 | U2 | Package_TO_SOT_SMD:SOT-223-3_TabPin2 | C6187

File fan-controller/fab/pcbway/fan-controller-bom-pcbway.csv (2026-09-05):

Item | Designator | Qty | Value | Package | Type | LCSC Part # | Note
1 | C1 | 1 | 220uF | CP_Radial_D8.0mm_P3.50mm | PTH |  | PTH - hand/wave solder; electrolytic cap 220uF 25V radial, 3.5mm pitch, max 8mm diameter, THROUGH-HOLE (not SMD)
2 | C2 | 1 | 10uF | C_0805_2012Metric | SMD | C440198
3 | D1 | 1 | SS34 | D_SMA | SMD | C8678
4 | F1 | 1 | 1.5A | Fuse_1812_4532Metric | SMD | C209713
5 | J1 | 1 | DC barrel jack 5.5x2.1mm | BarrelJack_CUI_PJ-102AH_Horizontal | PTH |  | PTH - hand/wave solder; DC barrel jack 5.5x2.1mm, horizontal/right-angle, 3 pins, CUI PJ-102AH or DC-005 compatible
6 | J2,J3,J4,J5 | 4 | 4-pin PC fan header | PinHeader_1x04_P2.54mm_Vertical | PTH |  | PTH - hand/wave solder; pin header 1x4 straight, 2.54mm pitch
7 | R1,R2,R3,R4 | 4 | 10k | R_0603_1608Metric | SMD | C25804
8 | R5,R6,R7,R8 | 4 | 1k | R_0603_1608Metric | SMD | C21190
9 | R9,R10,R11,R12 | 4 | 330 | R_0603_1608Metric | SMD | C23138
10 | U1 | 2 | 1x7 female header 2.54mm | XIAO-ESP32-C3-DIP | PTH | C5303 | PTH - hand/wave solder; female header 1x7 straight, 2.54mm pitch, row spacing 15.24mm - do NOT fit the module itself
11 | U2 | 1 | AMS1117-5.0 | SOT-223-3_TabPin2 | SMD | C6187

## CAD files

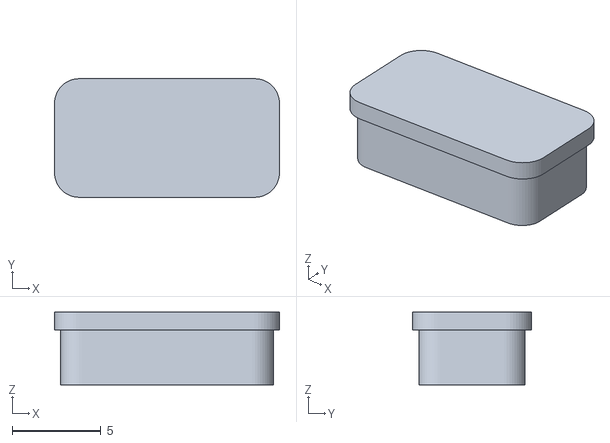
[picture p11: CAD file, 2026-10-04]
fan-housing/stl/fan-housing-guide.stl
12.7 x 6.70 x 4.10

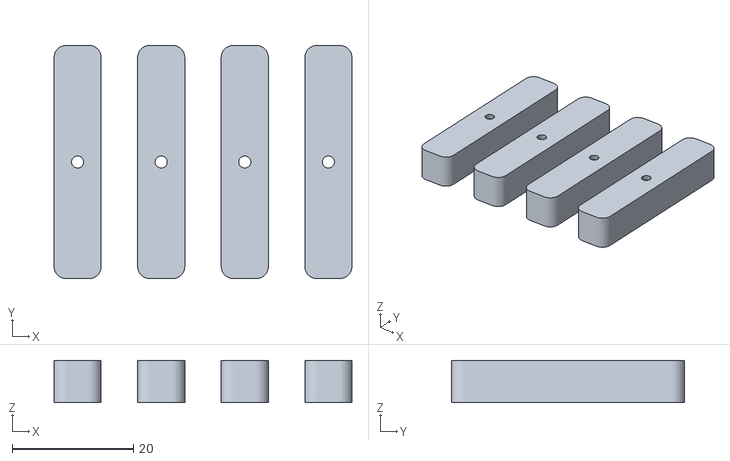
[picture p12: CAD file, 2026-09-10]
fan-mount/cad/ZapfenLarge.stl
49.2 x 38.5 x 7.00

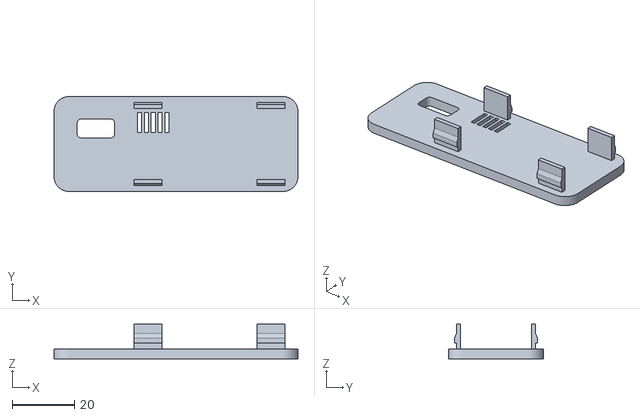
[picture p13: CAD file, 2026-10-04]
fan-housing/stl/fan-housing-lid.stl
78.5 x 30.6 x 11.1

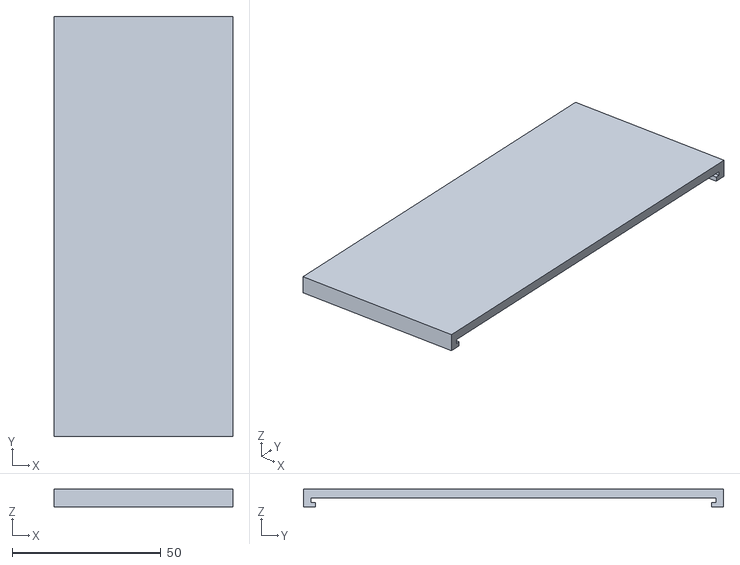
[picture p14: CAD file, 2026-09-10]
fan-mount/cad/passprobe_C.stl
60.0 x 141.0 x 5.90

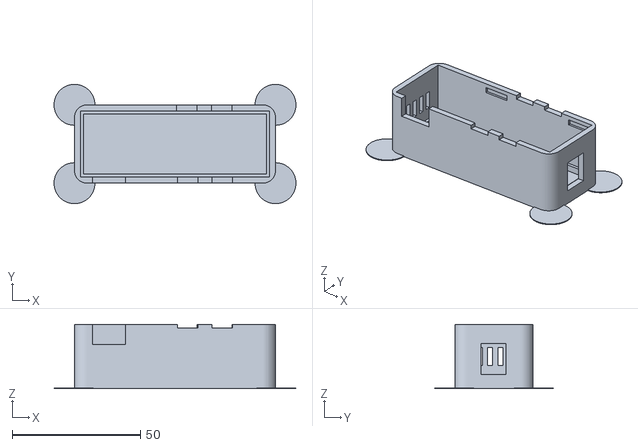
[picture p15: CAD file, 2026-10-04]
fan-housing/stl/fan-housing-tray.stl
94.5 x 46.6 x 25.1

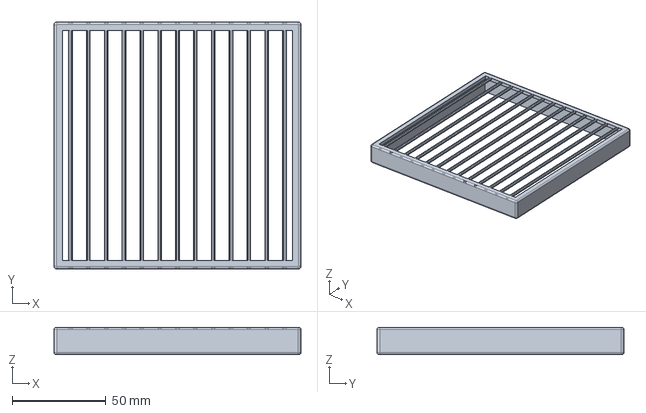
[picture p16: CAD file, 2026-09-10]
fan-mount/cad/RadiatorFanGuard.FCStd
131.6 x 131.6 x 14.5 mm

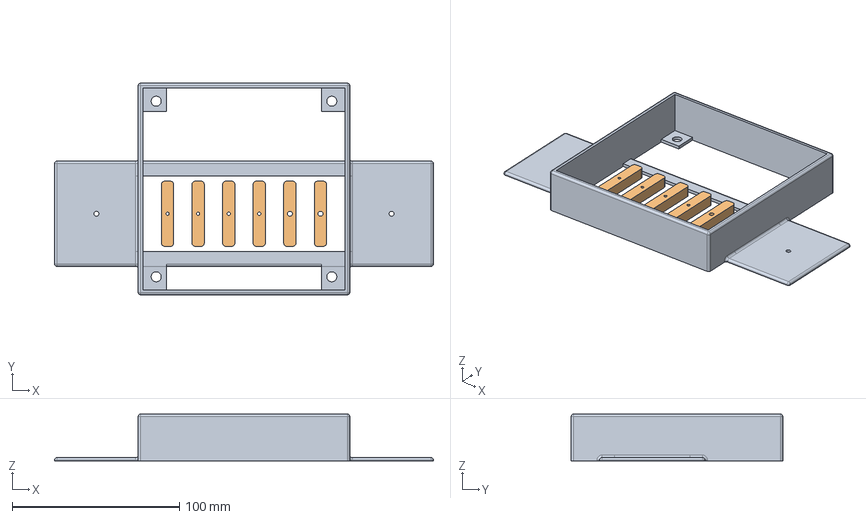
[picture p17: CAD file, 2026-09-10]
fan-mount/cad/passprobe.FCStd
226.6 x 126.6 x 28.0 mm
Halter A (Buero, 25-mm-Luefter)
Zapfen A (je 2x M2/M3/M4)

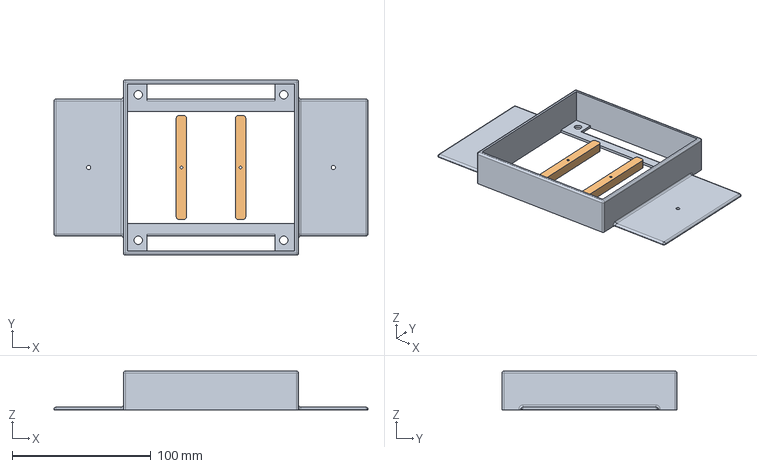
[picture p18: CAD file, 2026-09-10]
fan-mount/cad/RadiatorFanMedium.FCStd
226.6 x 126.6 x 28.0 mm
Halter RadiatorFanMedium
Zapfen (je 2x M2/M3/M4)

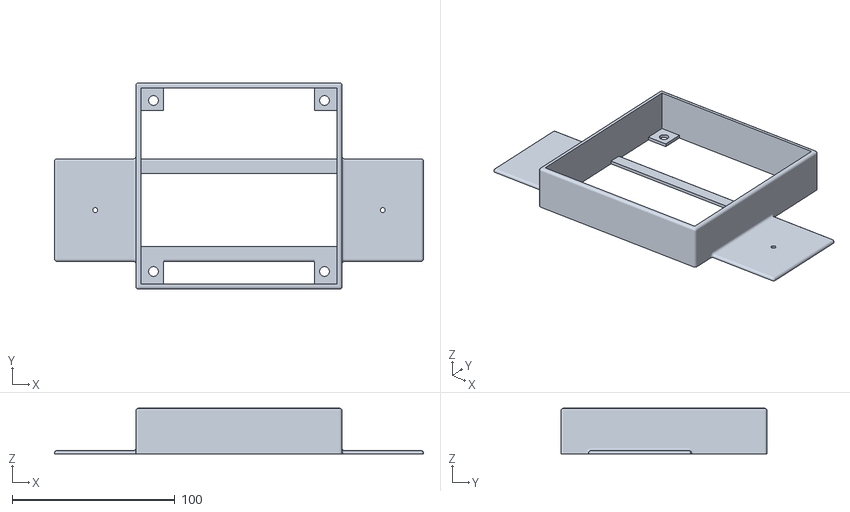
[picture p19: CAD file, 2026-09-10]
fan-mount/cad/halter_A.stl
226.6 x 126.6 x 28.0

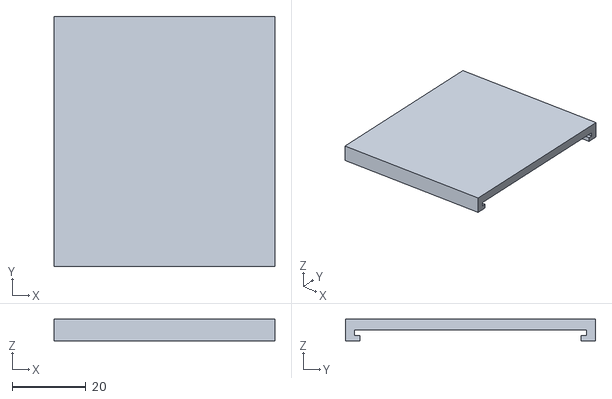
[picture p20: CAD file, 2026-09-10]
fan-mount/cad/passprobe_A.stl
60.0 x 68.0 x 5.90

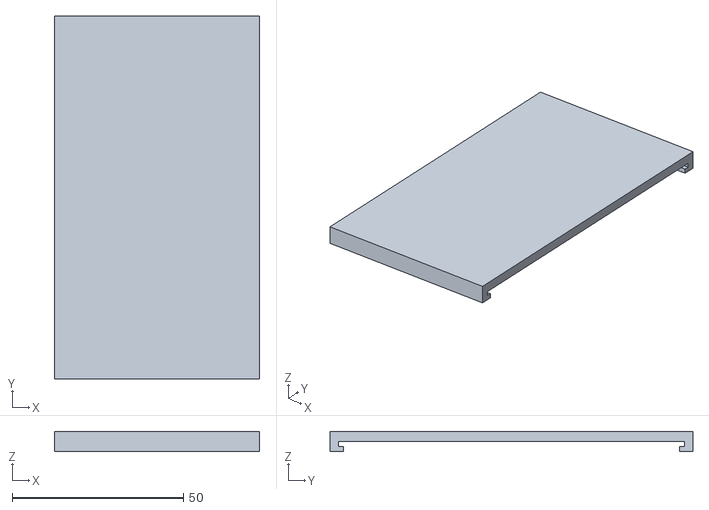
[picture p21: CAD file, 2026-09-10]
fan-mount/cad/passprobe_B.stl
60.0 x 106.0 x 5.90

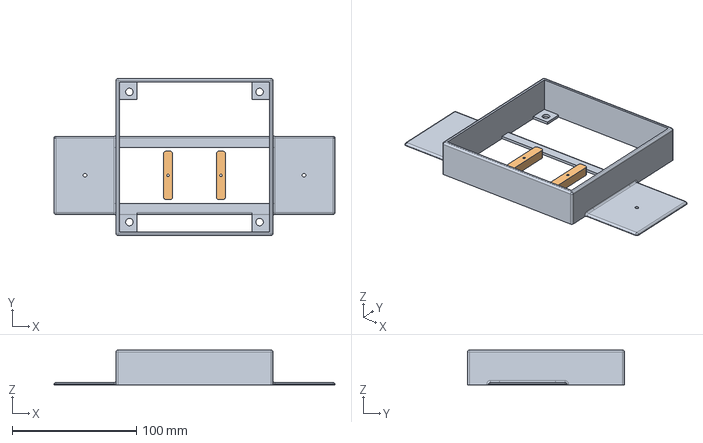
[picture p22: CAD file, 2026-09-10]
fan-mount/cad/RadiatorFanSmall.FCStd
226.6 x 126.6 x 28.0 mm
Halter RadiatorFanSmall
Zapfen (je 2x M2/M3/M4)

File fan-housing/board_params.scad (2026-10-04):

// GENERATED by fan-housing/extract_geometry.py
// Do not edit by hand - after a board change, run the script again.

board_l = 72.87;   // X, long side
board_w = 25.0;   // Y, short side

U1_x = [1.7249999999999999, 19.615];  U1_y = [1.905, 22.97];
J1_x = [60.825, 76.915];  J1_y = [6.455, 18.044999999999998];
J2_x = [35.815000000000005, 47.065000000000005];  J2_y = [1.185, 4.815];
J3_x = [49.235, 60.485];  J3_y = [1.185, 4.815];
J4_x = [35.465, 46.715];  J4_y = [20.185, 23.814999999999998];
J5_x = [49.045, 60.295];  J5_y = [20.185, 23.814999999999998];
C1_x = [25.872999999999998, 34.465];  C1_y = [9.953999999999999, 18.546];
U2_x = [23.075, 31.965];  U2_y = [1.355, 8.645];

antenna_x = [0.6699999999999999, 21.669999999999998];  antenna_y = [21.4, 25.0];

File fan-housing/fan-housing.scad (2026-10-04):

// ===========================================================================
//  Housing for the 4-channel fan controller (Seeed XIAO ESP32-C3)
//
//  Snap-fit, no screws: four spring tabs on the lid latch into pockets in the
//  tray. To open, press the long walls outward a little at the latch points.
//
//  All board dimensions come from board_params.scad, which
//  extract_geometry.py generates from the .kicad_pcb - do not change them here.
//
//  Parts to print:
//    part = "tray"   tray           (cream PETG)
//    part = "lid"    lid            (cream PETG)
//    part = "guide"  light guide    (transparent PETG)
//    part = "all"    assembly for inspection: solid tray, translucent lid
// ===========================================================================

include <board_params.scad>

part = "all";
only_tray = false;  // view option for part="all": show just the tray (with mouse ears), lid/board/guide hidden
$fn  = 48;

// Colours for the views only - cream PETG, clear light guide
col_case  = "antiquewhite";
col_guide = "lightcyan";

// ---------------------------------------------------------------- Material
wall     = 2.4;   // side walls
floor_t  = 2.0;   // tray floor
lid_t    = 3.1;   // lid. Deliberately thicker than the walls: cream PETG is
                  // still slightly translucent at 2.4mm, so an LED right
                  // underneath would show as a blotch.
                  //
                  // 3.1 and not 3.0: the layer boundaries sit at
                  // 0.3 + n*0.2, i.e. 2.9 and 3.1. At 3.0 the top of the
                  // lid falls in the MIDDLE of a layer, and the collar of
                  // the light guide claims the same one - the slicer then
                  // aborts with "found slicing result conflict".
                  // Found on the printed part on 2026-09-09: the window sat
                  // one layer too far back on the inside.
fit      = 0.4;   // clearance between board and inner wall (left, right, front, back)
ledge    = 1.2;   // width of the shoulder the board rests on
standoff = 2.5;   // space under the board for the solder joints
pcb_t    = 1.6;
inner_h  = 19.0;  // space above the top of the board. 15 + 4: the socketed XIAO
                  // sits 4mm higher than the catalogue values (see h_socket).
                  // The margin above the tallest part absorbs a 1mm error.
outer_r  = 4.9;   // outside corner radius (plan view). The inside is sharp-cornered
                  // like the board.

// ------------------------------------------------- component heights above PCB
// Not derivable from the .kicad_pcb - footprints carry no height.
h_socket   = 12.5;  // socketed XIAO: board underside above the PCB. Measured on the
                  // real assembly, 4mm more than the 8.5mm of a plain header.
h_xiao_pcb =  1.0;  // XIAO circuit board
h_usbc     =  3.3;  // USB-C receptacle above the XIAO board
h_fan      = 12.0;  // plugged-in fan connector (figure supplied by the owner)
h_jack     = 11.0;  // PJ-102AH body

h_xiao     = h_socket + h_xiao_pcb + h_usbc;   // 16.8 - tallest component

// The plugged-in fan connector is larger than the header underneath. The
// courtyard in the .kicad_pcb only describes the pin header, not its mating
// part - but for collisions the mating part is what counts.
fan_grow_x = 0.8;
fan_grow_y = 0.7;

// ---------------------------------------------------------------- options
usb_opening    = true;   // window for re-flashing without opening
usb_h          = 8.0;    // height of that window, centred on the USB-C receptacle
jack_trim      = 1.4;    // the jack opening is this much narrower than the jack, per side
ears           = true;   // 'mouse ears': thin discs at the four bottom corners that hold
                         // the tray down while it cools. Cut them off after printing.
ear_r          = 8.0;    // radius of an ear, centred on the outer corner
ear_t          = 0.3;    // thickness = one first layer
vents          = true;   // slots above the voltage regulator
light_window   = true;   // window + light guide above the XIAO
guide_loose    = false;  // true: clearance for inserting the guide afterwards,
                         // false: exact fit, printed together in one go
guide_collar_z = 0;      // extra gap between collar and lid underside (mm)
lid_recess     = false;  // recess in the lid for the collar (only for printing the guide in place)
guide_gap      = guide_loose ? 0.3 : 0;   // total clearance of the head in the window (mm)
guide_collar_h = 1.0;    // height of the collar (0 = none)
guide_collar_o = 1.0;    // overhang beyond the window, total. At 2.4 mm the slicer refuses lid and guide in one
                         // print ("gcode path conflicts ... found slicing result conflict"); 1.0 slices.

// ------------------------------------------------------------------ levels
// Z = 0 is the underside of the board.
z_floor_out = -standoff - floor_t;
z_floor_in  = -standoff;
z_pcb_top   = pcb_t;
z_rim       = pcb_t + inner_h;      // top of the tray, where the lid sits
z_lid_top   = z_rim + lid_t;

// ------------------------------------------------------------- footprint
ox0 = -(fit + wall);   oy0 = -(fit + wall);
outer_l = board_l + 2*(fit + wall);
outer_w = board_w + 2*(fit + wall);

// --------------------------------------------------------------- latches
// Positions along the length: free on both walls of components taller than
// the tab (fan connectors, XIAO, electrolytic cap, barrel jack).
snap_x     = [27.5, 67];
snap_len   = 9;
// Geometry of the spring tab. What matters is the outer-fibre strain at the
// root: eps = 3*t*d / (2*L^2). With t=1.4, d=0.6, L=8 that is about 2%;
// PETG yields at roughly 4-5%. The first design (t=1.6, L=6, d=0.7) came to
// 4.7% - the tab would have snapped off the first time the case was opened.
snap_t     = 1.4;        // thickness
snap_h     = 8.0;        // free length from the underside of the lid
snap_proud = 0.6;        // how far the nose protrudes
snap_gap   = 0.15;       // clearance between tab and inner wall
snap_pk_d  = 0.9;        // depth of the pocket in the wall (out of 2.4mm)

// ------------------------------------------------------- cable exits
notch_w     = 8.0;   // width of the slots for the fan cables
notch_depth = 1.5;   // depth below the top edge of the tray: the cable (0.9 mm) with margin
                     // between tray and lid

fan_x = [ (J2_x[0]+J2_x[1])/2, (J3_x[0]+J3_x[1])/2 ];   // lower long wall
fan_o = [ (J4_x[0]+J4_x[1])/2, (J5_x[0]+J5_x[1])/2 ];   // upper long wall

// ------------------------------------------------------------- light window
// Above the USB-C end of the XIAO - that is where the charge LED sits, and
// where a retrofitted status LED would make the most sense.
win_cx = (U1_x[0] + U1_x[1]) / 2;
win_w  = 12;
win_d  =  6;
win_cy = U1_y[0] + 5.6;   // behind the USB-C receptacle, the tallest part
                          // of the module - a foot in front of it would collide

// ===========================================================================
//  helper shapes
// ===========================================================================

module rrect(w, h, r) {
    hull() for (x = [r, w-r], y = [r, h-r]) translate([x, y]) circle(r = r);
}

// Cuboid from two corner points, handier than translate+cube
module box(x0, y0, z0, x1, y1, z1) {
    translate([x0, y0, z0]) cube([x1-x0, y1-y0, z1-z0]);
}

// ===========================================================================
//  Tray
// ===========================================================================

// Mouse ears: one-layer discs at the four bottom corners. A long, tall tray
// shrinks while it cools and peels up at its ends; the ears add bed contact
// exactly there. They are cut off after printing.
module mouse_ears() {
    for (x = [ox0, ox0 + outer_l], y = [oy0, oy0 + outer_w])
        translate([x, y, z_floor_out]) cylinder(r = ear_r, h = ear_t, $fn = 64);
}

module tray() {
    union() {
    difference() {
        translate([ox0, oy0, z_floor_out])
            linear_extrude(z_rim - z_floor_out)
                rrect(outer_l, outer_w, outer_r);

        // Interior above the underside of the board: the board drops in
        // from above
        translate([-fit, -fit, 0])
            linear_extrude(z_rim - 0 + 1)
                square([board_l + 2*fit, board_w + 2*fit]);

        // Space under the board. The difference to the interior above is the
        // shoulder the board rests on.
        translate([-fit + ledge, -fit + ledge, z_floor_in])
            linear_extrude(0 - z_floor_in + 0.01)
                square([board_l + 2*fit - 2*ledge,
                        board_w + 2*fit - 2*ledge]);
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

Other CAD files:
fan-mount/cad/RadiatorFanLarge.FCStd
fan-mount/cad/halter_A_komplett.stl
fan-mount/cad/RadiatorFanGuard.stl
fan-mount/cad/RadiatorFanLarge.stl
fan-mount/cad/RadiatorFanMedium.stl
fan-mount/cad/RadiatorFanSmall.stl

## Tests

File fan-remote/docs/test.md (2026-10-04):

# fan-remote — test plan

## Automated (no hardware)

```sh
pio test -e native
```

`lib/FanCore` is hardware-free and covered by 22 Unity tests: speed→duty mapping,
gentle first duty, start duty never above target, spin detection then slew, slew
limits, ramp-down then cut, blocked fan → fault without exceeding the ceiling,
retry with doubling/capped backoff and recovery, off clears the fault, a running
fan that stops, an already-turning fan, blind (no tach) mode, late ticks, `millis()`
wrap, RPM estimation (including 4 ppr, µs wrap, single-edge window), the MAC → number table
lookup and id format, and the standby policy (timeout, forced active, wake, `millis()` wrap).

The page is exercised against `scripts/mock_server.py` (see below). Run before every commit:
unit tests green, `pio run -e xiao_c3` without warnings.

## Web page against the mock

```sh
python3 scripts/mock_server.py 18099     # then open http://localhost:18099/
```

Check: phone width (≈390 px) and desktop; light and dark; German and English
(browser language); chip, slider drag, power button, all-fans card, stalled card;
settings dialog and save; no console errors.

## Hardware bring-up (once per board design, then spot checks)

Not covered by the automated tests; run with a scope or logic analyser and a real fan.

| # | Step | Expect |
|---|---|---|
| 1 | Flash over USB-C, open serial | `fan-remote <version>`; portal AP appears |
| 2 | Scope on FAN1 PWM, speed 50 | 25 kHz, 3.3 V, duty = `min + (max−min)·0.5` |
| 3 | Fan connected, speed 1 from standstill | slow duty rise; `Starting` → `Running`; no 100 % burst |
| 4 | Compare RPM with the fan's datasheet / a second tach reading | within a few % at 30, 60, 100 % |
| 5 | Tach unplugged, speed 50 | Stalled after ≈ 8 s (ramp + 3 s hold), PWM 0, retry in 15 s |
| 6 | Hold the rotor | Stalled within 5 s; release → recovers on retry |
| 7 | Unplug WiFi/router while running | fan unchanged; reconnects later |
| 8 | Reset the board while a fan runs | note the burst length (documents the PWM floating issue) |
| 9 | MQTT: set speed/preset/power, watch retained state | topics as in spec.md; HA entities appear |
| 10 | OTA update | succeeds; settings and last speeds survive |
| 10b | `pio run -e ota_c6 -t upload --upload-port fan-control-1` with the host firewall closed | upload succeeds, board returns with the new git id; `curl -F` without credentials → 401, without a file → 500, nothing reboots |
| 11 | Two boards | separate ids, two HA devices, no topic clashes |
| 12 | Find each fan's real *Min* | lowest duty that keeps it turning from a *running* state; set it in settings |

Done on the bench C6 with a fan on FAN1 (2026-10-04): steps 1, 3 (soft start observed, rpm ≈ 800
at speed 10), 9 (topics, HA entities), 10 (OTA, several times), plus standby: after 60 s
`power.mode` switches to `standby` at 80 MHz, PWM stays 25 000 Hz and the fan RPM is unchanged;
a wake request brings it back to 160 MHz and the next command takes ≈ 13 ms.

Status of this list: steps 2, 4–8, 11 and 12 are still open (the board has not been
tried on the fan PCB, and no scope was used).

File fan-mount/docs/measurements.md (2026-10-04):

# Radiator measurements

One table per radiator. These feed the FreeCAD spreadsheet directly.

Values already known are filled in. The **Status** column says how much to trust
each one:

| Status | Meaning |
|---|---|
| `measured` | Measured at the wall. Usable as a design input. |
| `photo` | Scaled off the steel rule in a photo. Indicative only — re-measure before it drives geometry. |
| `open` | Not yet determined. |

Photo references (`IMG_####`) are the original phone photos of 2026-08-16. They are not part of
this repository (40 MB of HEIC); [primer.html](primer.html) shows annotated crops of what each one shows.

Seven radiators, three families. Only the four panel radiators can take P1 as
conceived; see §"Non-panel radiators" below for the other three.

---

## Radiator 1 — Dining room

Long, low unit under a large window with a stone sill. Plants and lamps stand on
the sill directly above it. Photos: `IMG_7172`–`IMG_7177`.

| Key | Value | Status | Notes |
|-----|---|---|---|
| `type` | 22 or 33 | `photo` | Two fin banks visible (7174). 135 mm depth is deep for a 22 |
| `manufacturer` | | `open` | Look for a label on the end cap or behind the front panel |
| `length` | 1800–2200 mm | `photo` | Proportion against the window opening only (7172) |
| `height` | 220–230 mm | `photo` | Rule spans the full front face, both edges readable (7177) |
| `depth` | **136 mm** | `measured` | Sum of the partial lengths, 2026-08-17 (earlier estimated at 135/137) |
| `slot_width` | **8.0 mm** | `measured` | Web between slots 5.0 mm, pitch 13.0 mm |
| `channel_gap` | **22 mm** | `measured` | Unperforated centre web between the two perforated fields |
| `top_lip` | | `open` | |
| `grille_removable` | | `open` | **Priority 1** — see checklist |
| `side_covers_removable` | | `open` | |
| `headroom` | **50 mm** | `measured` | To underside of the stone sill |
| `floor_clearance` | | `open` | Looks small in 7172; may rule out P3 |
| `wall_standoff` | | `open` | |
| `fan_count` | 7–8 | derived | At one per 275 mm, pending real length |

**Fan fit:** 120 mm fan sits fully on the top face — the only radiator in the
house where it does. But 50 mm headroom leaves only 10–15 mm of intake plenum,
so use 15 mm slim fans and drop the finger guard.

---

## Radiator 2 — Living room

Long, low unit under a window with a stone sill. A floor fan already parked
beside it. Photos: `IMG_7178`–`IMG_7181`.

| Key | Value | Status | Notes |
|-----|---|---|---|
| `type` | 22 or 33 | `photo` | Two fin banks with a central gap (7181) |
| `manufacturer` | | `open` | |
| `length` | 2000–2400 mm | `photo` | Proportion against the window (7178) |
| `height` | 360–380 mm | `photo` | Rule shorter than the face, scaled by ratio (7179) |
| `depth` | **101 mm** | `measured` | Sum of the partial lengths, 2026-08-17 |
| `slot_width` | **7.7 mm** | `measured` | Web between slots 3.3 mm, pitch 11.0 mm |
| `channel_gap` | n/a | `measured` | Only ONE perforated field (75 mm), no centre web |
| `top_lip` | | `open` | |
| `grille_removable` | | `open` | **Priority 1** |
| `side_covers_removable` | | `open` | |
| `headroom` | **100 mm** | `measured` | To underside of the sill |
| `floor_clearance` | | `open` | Looks small in 7178/7179 |
| `wall_standoff` | | `open` | |
| `fan_count` | 7–9 | derived | Pending real length |

**Fan fit:** 120 mm fan overhangs ~10 mm each side. Let it overhang towards the
room, and add a short tapered plenum to gather the discharge onto the grille —
100 mm of headroom pays for that comfortably.

---

## Radiator 3 — Office

Panel radiator under a window with a stone sill. Boxes and a desk pushed against
it — access is poor. Photos: `IMG_7161`–`IMG_7164`.

| Key | Value | Status | Notes |
|-----|---|---|---|
| `type` | | `open` | Fin pack visible down the slot in 7164 but not countable |
| `manufacturer` | | `open` | |
| `length` | ~2000 mm | `photo` | Very rough (7161) |
| `height` | | `open` | |
| `depth` | **65 mm** | `measured` | Sum of the partial lengths, 2026-08-17 (the ruler had suggested 62) |
| `slot_width` | **7.6 mm** | `measured` | Web between slots 3.4 mm, pitch 11.0 mm |
| `channel_gap` | n/a | `measured` | Only ONE perforated field (39 mm), no centre web |
| `top_lip` | | `open` | |
| `grille_removable` | | `open` | |
| `side_covers_removable` | | `open` | |
| `headroom` | 40–70 mm | `photo` | Rule was in a different plane — unreliable (7161) |
| `floor_clearance` | | `open` | |
| `wall_standoff` | **~25 mm** | `measured` | Tight — the fan has to sit asymmetrically towards the front |
| `fan_count` | | `open` | |

**Fan fit — problem case.** A 120 mm fan is twice as wide as this radiator is
deep; roughly two thirds of its discharge would miss the grille. Either drop to
60 mm fans (noisy for the air they move) or use a tangential blower, whose
roller is naturally 60–80 mm across and the right shape for a long narrow slot.
Decide this before designing a P1 variant for this room.

---

## Radiator 4 — Guest WC

Small panel radiator on the tiled wall behind the toilet, valve bottom right.
No windowsill above it. Photos: `IMG_7165`–`IMG_7167`.

| Key | Value | Status | Notes |
|-----|---|---|---|
| `type` | 11 or 21 | `photo` | Only one fin bank visible down the slot (7167) |
| `manufacturer` | | `open` | |
| `length` | ~600 mm | `photo` | Counted against wall tiles of assumed size (7165) |
| `height` | ~500 mm | `photo` | Same method — low confidence |
| `depth` | | `open` | **The one depth still completely unknown** |
| `slot_width` | | `open` | Grille slot pitch 11–12 mm (`photo`, 7166) |
| `channel_gap` | | `open` | If Type 11, there is no channel |
| `top_lip` | | `open` | |
| `grille_removable` | | `open` | |
| `side_covers_removable` | | `open` | |
| `headroom` | | `open` | Probably unlimited — no sill seen in 7165 |
| `floor_clearance` | n/a | — | Wall-hung, well above the floor |
| `wall_standoff` | | `open` | |
| `fan_count` | 2 | derived | At one per 275 mm, pending real length |

**Fan fit:** unknown until depth is measured. At ~600 mm long this is the
smallest job in the house and a good candidate for the first prototype — if the
depth allows a 120 mm fan.

---

## Non-panel radiators

These three have no top slot and no convector fins. P1 does not apply; they need
a different part family, and it is a live question whether they stay in scope at
all. Only fill these in if they do.

### Radiator 5 — Main bathroom, towel rail

Horizontal round tubes on two vertical side collectors. Usually covered in
towels, which will block most of any forced airflow. Photos: `IMG_7156`–`IMG_7160`.

| Key | Value | Status |
|-----|---|---|
| `tube_diameter` | | `open` |
| `tube_pitch` | | `open` (centre to centre) |
| `collector_spacing` | | `open` |
| `length` / `height` | | `open` |
| `wall_standoff` | | `open` |

**Concept:** fan turned on its side on a clip-on bracket gripping two tubes,
blowing horizontally through the gaps. See FIG 8 in [primer.html](primer.html).

### Radiator 6 — Second bathroom, vertical tube radiator

Tall, narrow two-column radiator beside the mirror and sink.
Photos: `IMG_7168`–`IMG_7169`.

| Key | Value | Status |
|-----|---|---|
| `tube_diameter` | | `open` |
| `tube_pitch` | | `open` |
| `length` / `height` | | `open` |
| `wall_standoff` | | `open` |

### Radiator 7 — Old sectional radiator

Cast-style ribbed sections with corrosion at the section joints. Tight niche.
Photos: `IMG_7170`–`IMG_7171`.

| Key | Value | Status |
|-----|---|---|
| `section_pitch` | | `open` |
| `section_count` | | `open` |
| `top_profile_height` | | `open` (hump to valley) |
| `height` | | `open` |
| `wall_standoff` | | `open` |

**Concept:** a saddle bracket straddling the humped top, feet in the valleys,
blowing down the gaps between sections. Downdraft still works here — the top is
just not flat. Note the corrosion before investing effort in this one.

---

## Perforated-sheet geometry (measured 2026-08-17)

Top view across the wall. Layout: `edge | perforated field | [centre web | perforated field] | edge`.
The depth is the **sum** of these partial lengths — for all three it adds up.

| | A — Office | B — Living room | C — Dining room |
|---|---|---|---|
| Depth (sum) | 65 mm | 101 mm | 136 mm |
| Edge strip | 13 | 13 | 17 |
| Perforated field | 39 | 75 | 40 (×2) |
| Centre web | — | — | 22 |
| Slot width | 7.6 | 7.7 | 8.0 |
| Web between slots | 3.4 | 3.3 | 5.0 |
| **Pitch** | **11.0** | **11.0** | **13.0** |

**A and B are the same design in two sizes** — same 11 mm pitch, same edge strip. C has a pitch
of its own, 13 mm, and is the only one with an unperforated centre web on which a mount can rest.

Machine-readable in [../cad/radiator_sheets.csv](../cad/radiator_sheets.csv).

### Still open on the perforated sheets

- **Slot length in the direction of the wall** — short oblong holes or continuous? Decides whether
  pegs fit into the pitch at all.
- **Sheet thickness** — 0.8 or 1.0 mm? The fit-test frames assume 1.0 mm.
- **Free sheet edge?** The edge grip needs an edge it can grip. If the grid turns into a bead or a
  side panel, the principle fails — the fit-test frames check that first. (The finished mounts no
  longer use an edge grip; they are held by pegs in the slots.)

### Height budget

Clear height minus base plate (3 mm) minus fan gives the intake space; a 120 mm fan wants ~30 mm of it.

| | Clear height | with 15 mm slim fan | with 25 mm fan |
|---|---|---|---|
| A — Office | ~55 mm | 37 mm — good | 25 mm — tight |
| B — Living room | 100 mm | 82 mm — good | 70 mm — good |
| C — Dining room | 50 mm | 32 mm — good | 20 mm — tight |

The design point is therefore a **15 mm slim fan, 3 mm base plate**. B is the most comfortable case,
not the tightest.

---

# Measurement checklist

In priority order. Items 1 and 2 can still change what the parts are, so do them
first.

- [ ] **1. Does the top grille or front cover lift off?**
      Dining room and living room. Try lifting the full-length grille, then
      pulling the front panel forward off its clips. If either comes away, fans
      can sit *inside* the casing blowing up through the grille — which removes
      the headroom and intake-plenum problems entirely and changes P1 from a
      collar into an internal cradle. Also settles whether these are panel
      radiators or convector casings.

- [x] **2. `channel_gap` — done for A, B, C** (2026-08-17).
      C has a 22 mm centre web; A and B have only one perforated field, so none.
      Still open only for the guest WC.

      ~~Original:~~
      Caliper jaws down through the top slot until they touch the fin tips on
      both sides. *Not* the sheet-metal slot above it — they differ. In
      `IMG_7181` this is the dark band running between the two rows of wavy
      fins. Decides whether P1 ducts into the channel or seals flat on the
      grille face.

- [ ] **3. `depth` — guest WC.**
      Rule flat across the end cap, front face to back face. The shot in
      `IMG_7176` is the right technique. Depth decides fan diameter, so this is
      a real gap.

- [ ] **4. `headroom` — office and guest WC.**
      Rule standing on the radiator top, hard against the wall; read where the
      underside of the sill crosses it. Do it at one end and again in the
      middle — sills are rarely level. The guest WC may have no sill at all, in
      which case it is unlimited.

- [x] **5. `slot_width` — done for A, B, C** (2026-08-17): 7.6 / 7.7 /
      8.0 mm, see the perforated-sheet table above. Still open for the guest WC.

      ~~Original:~~
      Rule flat across the top, measuring the opening in the pressed steel —
      the feature seen edge-on in `IMG_7163` and `IMG_7166`. Sets the collar
      footprint if the seal-on-grille approach wins.

- [ ] **6. `length` and `height`, all four.**
      Tape along the wall, and floor to top edge. These drive fan count and the
      P2 tile lengths. Millimetre precision not needed.

- [ ] **7. `floor_clearance`, all four.**
      Floor to bottom edge. In `IMG_7178` and `IMG_7179` the units look like
      they nearly reach the skirting, which would rule out a bottom-mounted
      deflector (P3) as well as any fallback to upward flow.

- [ ] **8. `wall_standoff`, all four.**
      Back face to wall. Sets how far the magnet skirt can reach round.

- [ ] **9. `top_lip`, all four.**
      Thickness and profile of the top edge the hanger hooks over.

- [ ] **10. Tube diameter and pitch — the two bathrooms.**
      Only if the tube radiators stay in scope. Caliper across one tube, then
      centre to centre between two adjacent ones.

---

# How to measure the awkward ones

## `channel_gap`

The critical one for P1. Look down through the top slot: on a Type 22 you see
two fin packs facing each other with a gap between them. That gap is what the
fan blows into, and it sets the maximum width of the mount's duct section.
Measure the *clear* distance between the fin tips, not the slot in the sheet
metal above it — they are usually different.

If the top grille lifts off, measure with it removed and note both values.

Current best estimate is 10–15 mm (living room, `IMG_7181`). If that holds, a
duct collar reaching down into the channel is not buildable and P1 seals flat on
the grille face instead.

## `headroom`

Stand the rule on the radiator's top surface, hard against the wall, and read
where the underside of the sill crosses it. Not the sill's front edge — the
overhang is not what limits the fan.

What actually matters is not the total gap but what is left above the fan once
the stack is in: fan body + collar + compressed seal. An axial fan wants roughly
a quarter of its diameter of free space on the suction side to draw evenly —
about 30 mm for a 120 mm fan. Below that it loses flow and starts to whistle.

## `depth` and fan diameter

Depth sets the width of the top face, which is all the area available to accept
the fan's discharge. If the fan is wider than the radiator is deep, the surplus
blows at the sill and the wall and does no work.

Rough rule: fan diameter ≤ depth for a direct fit; up to about 1.2 × depth if
there is headroom for a tapered plenum; beyond that, change fan size or switch
to a tangential blower.

## Photographing instead of measuring

Only worth it if the rule lies flat against the feature with its zero mark and
the far edge both in frame and in focus. Most of the original photos fail that
test, which is why so much here is still `open`. Shoot straight on, not at an
angle. For a fine scale, crop tight to the feature *before* resizing — cropping
preserves detail that downscaling destroys.

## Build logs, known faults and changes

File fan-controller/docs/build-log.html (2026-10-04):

Build log · ESP32-C3 fan controller

# From a 555 sketch to a panelised order

A four-channel PC fan controller, designed in KiCad over a handful of sessions and sent to PCBWay fully assembled. This is the route it actually took — including the wrong turns, which were the expensive part.

72.9 × 25.0 mm 2-layer 23 components 10 units €75.77 assembled KiCad 10.0.5

## Stage 01

### The scope moved before a single part was placed

The opening question was for the simplest possible circuit to hold a 4-pin PC fan at a fixed speed. The honest answer is a 555 timer generating 25 kHz PWM — or, simpler still, a 9 V supply instead of 12 V and no electronics at all.

That answer was correct and immediately obsolete: if the board was going to exist, it should drive four fans and take commands over WiFi. The 555 never made it into a schematic. What replaced it was a Seeed XIAO ESP32-C3 on a socket, four fan headers, and the small amount of glue needed to get 12 V in and PWM out.

MCU

Seeed XIAO ESP32-C3, socketed on 2× 1×7 female headers

Per channel

PWM out through 1 kΩ; tach in through 330 Ω, pulled up 10 kΩ to 3V3

Power

Barrel jack → SS34 reverse-polarity diode → 1.5 A polyfuse → AMS1117-5.0

GPIO

D1/D2, D3/D4, D7/D10, D5/D6 — D0, D8, D9 avoided as strapping pins

Design rule

The ESP32-C3 strapping pins are not a suggestion. D9 in particular has a documented boot failure when a transistor is attached to it, so all eight fan signals were placed on D1–D7 and D10 — exactly eight clean pins, with nothing to spare.

## Stage 02

### The schematic is generated, not drawn

Every connection lives in one Python file as a (ref, pin) → net table. A single command rebuilds the whole sheet from it: placement, wires, labels, structural repair, and a netlist audit that diffs the result back against the table.

That indirection paid for itself the first time a channel needed re-assigning. Swapping FAN1 with FAN2 is a two-line edit and a re-run, not an afternoon of re-drawing.

The fan controller schematic: XIAO module at left, power chain across the top, four fan channels stacked at right

Signals left to right, power top to bottom. Wires where the hop is local; labels for the rails and for anything crossing the sheet.

The expensive mistake

Two full wiring attempts were scrapped before the cause surfaced. Symbol libraries store pin offsets with +y up; the schematic canvas uses +y down. Absolute pin position is therefore place_y - local_y, not plus.

Getting that sign wrong mirrors every pin about its own symbol origin, so wires attach to the pin on the opposite side of the part — the XIAO's VBUS resolved to D9/BOOT. ERC passes cleanly, because landing on the wrong real pin is still a perfectly valid connection. Only a pin-by-pin netlist audit catches it.

Two smaller traps sat behind it. KiCad rewrites the file with each field on its own line as soon as the GUI touches it, so any parser keyed to the single-line form silently finds zero symbols. And symbols defined with extends — most fixed-voltage regulators — inherit their pins from a base symbol, so copying the derived symbol alone yields a part with no pins at all.

## Stage 03

### Placement by hand, because the board is the constraint

Footprints were imported programmatically with their nets attached, then arranged by hand. The board is 25 mm tall and every millimetre is spoken for: the XIAO occupies the left third, the power chain runs along the top, and the four fan channels stack on the right, each with its own three resistors.

Top view of the finished board: XIAO socket at left, power section centre, four fan headers and resistor columns at right, barrel jack on the right edge

Top side, all 23 parts. The barrel jack sits on the right edge with its flange on the board outline — the 3.5 mm of barrel beyond is the socket nose, meant to protrude.

The outline was fitted last, 1 mm clear of all copper, which took the board from 80 × 60 mm down to 72.9 × 25.0 mm — a 54% reduction in area before the final trim.

Watch the connector

The jack was initially placed mid-board, then moved to the edge, then tucked inward when its flange sat 1.9 mm proud of the outline. The tuck stopped at 1.8 mm: beyond that, F1's pad and the +12V_IN trace collide with the +12V_PROT trunk running vertically through the same corridor.

A 3 mm move was requested and refused with the reason, rather than applied and left to fail DRC.

## Stage 04

### Routing by hand — and ground on the back with real wires

Automatic routing was never attempted. The board was routed manually in the KiCad GUI, where the ratsnest and live DRC make a mistake visible the moment it happens.

Method that worked

Route ground as ordinary wires on the back side, and pour the plane only at the very end. A plane laid early hides missing connections — every stray pad looks connected because copper happens to touch it. Wiring ground explicitly means the ratsnest stays honest until the layout is genuinely finished.

Power widths came from IPC-2152 for 1 oz copper at a 10 K rise. A single uniform width does not fit: the corridor around the XIAO is a 2.54 mm pad pitch. So every power segment starts at its target and steps down only where DRC objects.

Net | Width | Capacity | Carries
+12V_IN / _FUSED / _PROT | 1.0 mm | 2.39 A | four fans through a 1.5 A polyfuse
GND | 1.0 mm | 2.39 A | the same current, returning
+5V | 0.6 mm | 1.65 A | the XIAO, ~100 mA
+3V3 | 0.6 mm | 1.65 A | four pull-ups, under 2 mA
signals | 0.2 mm | 0.74 A | microamps

Two GND segments stayed at 0.2 mm, wedged between XIAO pads. Sampling along their length found ground-plane copper beneath at 28 of 33 points, and the XIAO's ground pad is a through-hole tied into the plane — so the plane carries that return in parallel and width is not the limit there. A temporary marker layer flagged every undersized segment during rework, then was removed.

## Stage 05

### The plane goes last, with a hole cut for the antenna

Only once every net was routed did the ground pour go down on the back side: 1417 mm² of copper with thermal relief on pads. Unconnected items dropped from 16 to 1 the moment it filled.

Bottom view showing the ground plane with a rectangular keep-out cut away above the XIAO module's antenna end

Back side, viewed through the board. The dark notch at upper right is the antenna keep-out — copper pulled back from the XIAO's radio end.

Find the antenna properly

The XIAO is rotated −90° on this board, which puts pins 7 and 8 at the same y — the module's top edge, opposite the USB connector. That is where the PCB antenna sits. The keep-out spans that edge out to the board boundary and stops 0.52 mm short of those two pads; a first attempt ran 1.4 mm further and DRC correctly rejected it for swallowing them.

## Stage 06

### The fab package is where the real formats bite

One script produces gerbers, Excellon drill, BOM and pick-and-place. Three defaults in that chain are wrong for a real order.

#### Gerbers export every layer unless told otherwise

A bare kicad-cli pcb export gerbers wrote a 152 KB User_Eco1.gbr containing the internal review markers. The layer list has to be explicit.

#### Column headers are not negotiable at JLCPCB

KiCad writes Ref, Val, Package, PosX, PosY, Rot, Side. JLCPCB wants Designator, Mid X, Mid Y, Layer, Rotation — different names, different order, Top rather than top. The coordinates were right all along; only the header was rejected.

#### BOM and CPL are matched designator by designator

Collapsing four resistors to R1-R4 reads well to a human and fails the import: the CPL lists them individually, so the range matches nothing. Full comma lists only.

The part with no symbol

The XIAO is socketed, so what actually gets assembled is two 1×7 female headers — and they have no schematic symbol at all. Their holes are the 14 through-hole pads of the module's own footprint.

Invented designators (U1-SKT1) fail, because the fab matches BOM against CPL and those exist in neither. The working answer is to let U1 be the socket position: its comment describes the headers, and the module is plugged in afterward. That is the physical truth — sockets sit there, not a module.

## Stage 07

### Two fabs, two different packages

JLCPCB's catalogue is SMD-oriented and carried none of the through-hole parts, so that route means assembling 16 SMD positions and hand-soldering the rest. PCBWay offers through-hole assembly as a standard service, so there the whole board is populated — all 23 positions, BOM and CPL both including the THT parts.

| JLCPCB | PCBWay
Positions | 16 — SMD only | 23 — all
Format | strict headers, rejects on mismatch | tolerant; reviewed by a person
Part selection | self-service catalogue, live preview | quoted by email, substitutions offered
Through-hole | solder yourself | hand / wave soldered

Because PCBWay's staff read the BOM, the notes column does real work there: C1 is marked through-hole, not SMD, and U1 carries the full explanation of the socket arrangement. Both survived into the quote intact.

Still open on the quote

U1 is quoted at qty 1 — 10 headers for 10 boards. Two are needed per board. The quantity column tracks the designator list, so it cannot express “one footprint, two parts”; the count was moved into the value field (2x 1x7 female header) and the note, but the pricing followed the column.

Worth €0.80 and one email before assembly starts.

## Stage 08

### What it cost

Ordered from PCBWay: turnkey, 10 units, one day for fabrication and 28–31 days for assembly.

Line | €
Components | 29.06 | barrel jack alone is 12.55
Assembly | 29.00 | SMT plus through-hole
PCBs | 18.18
Member discount | −0.47
Total, 10 units | 75.77 | €7.58 per board

A cheaper route was investigated and rejected. Four boards panelised on one 100 × 100 mm panel is exactly 100.0 mm with zero gap, and the board cannot shrink: the +12V_PROT traces already sit at the 0.5 mm design-rule minimum from both edges. Three-up fits, but means hand-soldering roughly 240 0603 resistors for the saving.

Before the panels ship

Check the assembly preview for rotation. KiCad and the fabs use different zero orientations for the same packages, so U2 (SOT-223 — the tab must land on the wide pad) and D1 (cathode direction) need eyes on them. The resistors, ceramic cap and polyfuse are unpolarised and cannot be got wrong.

Fan controller · Joachim Banzhaf · 2026 72.9 × 25.0 mm · 2 layer · 1 oz

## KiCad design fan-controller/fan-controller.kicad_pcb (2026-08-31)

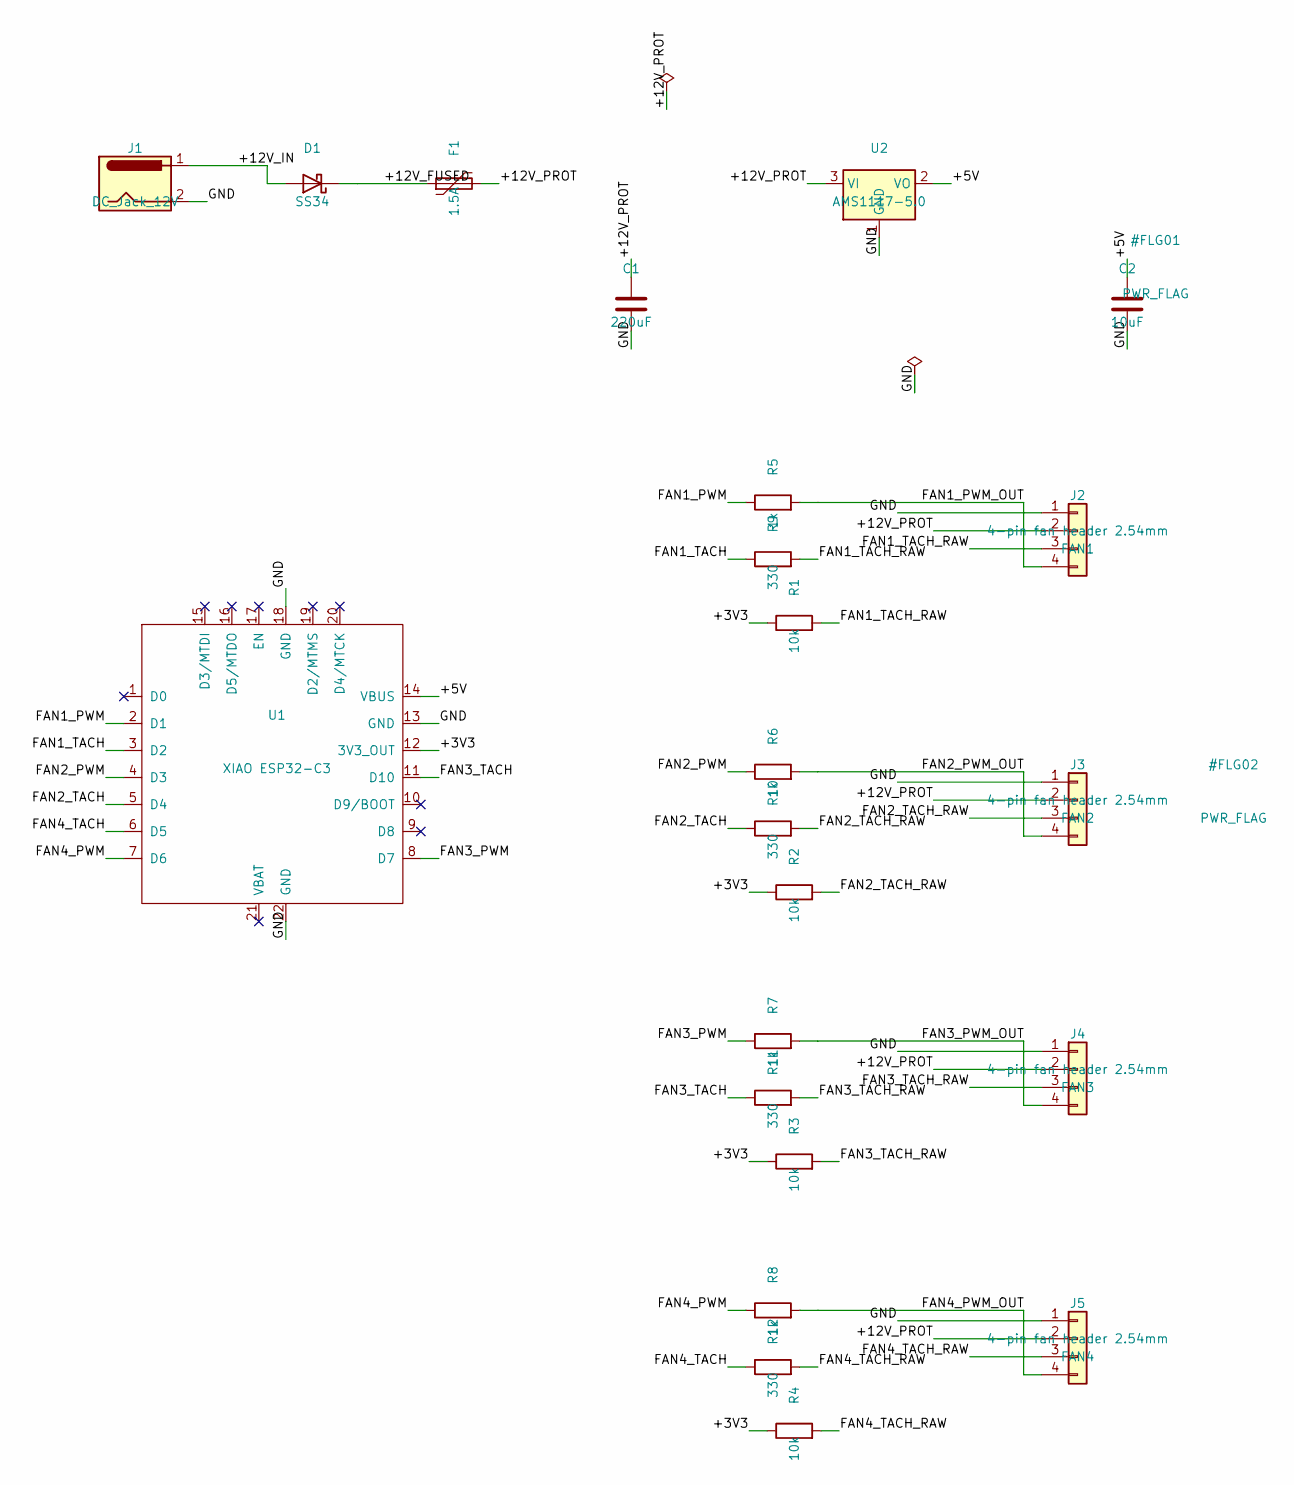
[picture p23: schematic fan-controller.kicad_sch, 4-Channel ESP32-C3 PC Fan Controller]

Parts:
C1: 220uF; CP_Radial_D8.0mm_P3.50mm
C2: 10uF; C_0805_2012Metric
D1: SS34; D_SMA
F1: 1.5A; Fuse_1812_4532Metric
J1: DC_Jack_12V; BarrelJack_CUI_PJ-102AH_Horizontal
J2: FAN1; PinHeader_1x04_P2.54mm_Vertical
J3: FAN2; PinHeader_1x04_P2.54mm_Vertical
J4: FAN3; PinHeader_1x04_P2.54mm_Vertical
J5: FAN4; PinHeader_1x04_P2.54mm_Vertical
R1, R2, R3, R4: 10k; R_0603_1608Metric
R5, R6, R7, R8: 1k; R_0603_1608Metric
R9, R10, R11, R12: 330; R_0603_1608Metric
U1: XIAO ESP32-C3; XIAO-ESP32-C3-DIP
U2: AMS1117-5.0; SOT-223-3_TabPin2

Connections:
/+3V3: R1.1, R2.1, R3.1, R4.1, U1.12 (3V3_OUT)
/+5V: C2.1, U1.14 (VBUS), U2.2 (VO)
/+12V_FUSED: D1.1 (K), F1.1
/+12V_IN: D1.2 (A), J1.1
/+12V_PROT: C1.1, F1.2, J2.2, J3.2, J4.2, J5.2, U2.3 (VI)
/FAN1_PWM: R5.1, U1.2 (D1)
/FAN1_PWM_OUT: J2.4, R5.2
/FAN1_TACH: R9.1, U1.3 (D2)
/FAN1_TACH_RAW: J2.3, R1.2, R9.2
/FAN2_PWM: R6.1, U1.4 (D3)
/FAN2_PWM_OUT: J3.4, R6.2
/FAN2_TACH: R10.1, U1.5 (D4)
/FAN2_TACH_RAW: J3.3, R2.2, R10.2
/FAN3_PWM: R7.1, U1.8 (D7)
/FAN3_PWM_OUT: J4.4, R7.2
/FAN3_TACH: R11.1, U1.11 (D10)
/FAN3_TACH_RAW: J4.3, R3.2, R11.2
/FAN4_PWM: R8.1, U1.7 (D6)
/FAN4_PWM_OUT: J5.4, R8.2
/FAN4_TACH: R12.1, U1.6 (D5)
/FAN4_TACH_RAW: J5.3, R4.2, R12.2
/GND: C1.2, C2.2, J1.2, J2.1, J3.1, J4.1, J5.1, U1.13 (GND), U1.18 (GND), U1.22 (GND), U2.1 (GND)

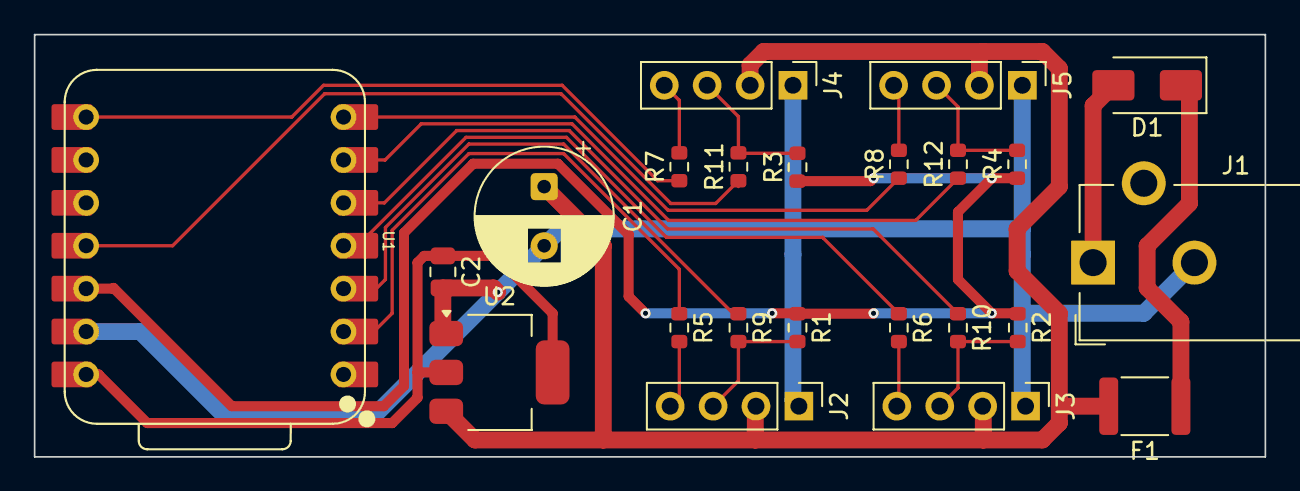
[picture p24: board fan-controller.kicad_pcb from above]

Board: 2 copper layers, 72.9 x 25.0 mm, 23 parts (0 on the bottom side), 22 nets.

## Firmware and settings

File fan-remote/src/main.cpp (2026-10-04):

// fan-remote — firmware for the 4-channel fan controller (XIAO ESP32-C3).
// See docs/spec.md. The fans run in their own task (Fans.cpp); this file wires up the
// network side and persists the speeds.
#include <Arduino.h>

#include "Fans.h"
#include "Led.h"
#include "Mqtt.h"
#include "Net.h"
#include "Power.h"
#include "NetLog.h"
#include "Settings.h"
#include "Web.h"

static uint8_t savedSpeed[kFans];
static uint32_t changedAt = 0;
static bool dirty = false;

static void persistSpeeds() {
  // Write the target speeds 5 s after the last change: sliders must not wear the flash.
  Settings &s = settings();
  bool differs = false;
  for (int i = 0; i < kFans; i++)
    if (s.lastSpeed[i] != savedSpeed[i]) differs = true;
  if (differs && !dirty) {
    dirty = true;
    changedAt = millis();
  }
  if (dirty && millis() - changedAt > 5000) {
    settingsSaveSpeeds();
    for (int i = 0; i < kFans; i++) savedSpeed[i] = s.lastSpeed[i];
    dirty = false;
  }
}

void setup() {
  Fans::earlyInit();  // PWM pins low first, before anything can take time
  Serial.begin(115200);
  settingsLoad();
  logf(LOG_INFO, "fan-remote %s (%s) %s", FW_VERSION, FW_GIT, deviceId());

  fans.begin();
  powerBegin();
  Settings &s = settings();
  for (int i = 0; i < kFans; i++) savedSpeed[i] = s.lastSpeed[i];
  if (s.bootMode == 0) {
    for (int i = 0; i < kFans; i++)
      if (s.lastSpeed[i] && s.ch[i].enabled) fans.setSpeed(i, s.lastSpeed[i]);  // soft start
  }

  ledBegin();
  mqttBegin();
  netBegin();     // may take up to ~20 s; the fans do not care
}

static bool webUp = false;

void loop() {
  netLoop();
  // The setup portal and the web server both want port 80: start the server only once
  // WiFi is connected and the portal is gone.
  if (!webUp && netConnected() && !netPortalActive()) {
    webBegin();
    webUp = true;
  }
  fans.logEvents();
  ledLoop();
  powerLoop();
  netlogLoop();
  mqttLoop();
  if (webUp) webLoop();
  persistSpeeds();
  delay(5);
}

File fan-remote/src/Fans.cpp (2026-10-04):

#include "Fans.h"

#include <esp_task_wdt.h>
#include <esp_timer.h>

#include <mutex>

#include "NetLog.h"

Fans fans;

// Board: FAN1 PWM=D1 TACH=D2, FAN2 D3/D4, FAN3 D7/D10, FAN4 D6/D5 (verified against
// fan-controller.kicad_pcb).
static const uint8_t kPwmPin[kFans] = {D1, D3, D7, D6};
static const uint8_t kTachPin[kFans] = {D2, D4, D10, D5};

constexpr uint32_t kPwmHz = 25000;   // Intel 4-wire fan spec
constexpr uint8_t kPwmBits = 10;
constexpr uint32_t kPwmMax = (1u << kPwmBits) - 1;
constexpr uint32_t kTickMs = 20;
constexpr uint32_t kRpmWindowMs = 1000;
constexpr uint32_t kGlitchUs = 1500;  // tach edges closer than this are noise

struct Tach {
  volatile uint32_t total = 0;       // all edges ever, drives FanCore
  volatile uint32_t winCount = 0;    // edges in the current RPM window
  volatile uint32_t winFirst = 0;
  volatile uint32_t winLast = 0;
  volatile uint32_t lastUs = 0;
};

static Tach tach[kFans];
static portMUX_TYPE tachMux = portMUX_INITIALIZER_UNLOCKED;

static void IRAM_ATTR tachIsr(void *arg) {
  Tach *t = static_cast<Tach *>(arg);
  uint32_t now = (uint32_t)esp_timer_get_time();
  if ((uint32_t)(now - t->lastUs) < kGlitchUs) return;
  t->lastUs = now;
  t->total = t->total + 1;
  if (t->winCount == 0) t->winFirst = now;
  t->winLast = now;
  t->winCount = t->winCount + 1;
}

static fancore::Channel chan[kFans];
static fancore::RpmMeter meter[kFans];
static uint32_t windowStart[kFans];
static uint32_t lastDuty[kFans];
static uint8_t lastSpeedSeen[kFans];
static fancore::State lastState[kFans];
static bool lastFault[kFans];
static uint32_t rev = 1;
static volatile uint8_t event[kFans];   // 1 = stalled, 2 = turning again
static std::mutex mu;

void Fans::earlyInit() {
  for (int i = 0; i < kFans; i++) {
    pinMode(kPwmPin[i], OUTPUT);
    digitalWrite(kPwmPin[i], LOW);
  }
}

void Fans::configureChannel(int i) {
  const Settings &s = settings();
  fancore::ChannelParams p;
  p.minPct = s.ch[i].minPct;
  p.maxPct = s.ch[i].maxPct;
  p.startPct = s.ch[i].minPct < 15 ? s.ch[i].minPct : 15;
  p.tach = s.ch[i].tach;
  p.rampUpPctS = s.rampUp ? s.rampUp : 1;
  p.rampDownPctS = s.rampDown ? s.rampDown : 1;
  chan[i].configure(p);
  meter[i].setPulsesPerRev(s.ch[i].ppr);
}

void Fans::begin() {
  for (int i = 0; i < kFans; i++) {
    configureChannel(i);
    ledcAttach(kPwmPin[i], kPwmHz, kPwmBits);
    ledcWrite(kPwmPin[i], 0);
    pinMode(kTachPin[i], INPUT);  // 10k pull-up to 3V3 is on the board
    attachInterruptArg(digitalPinToInterrupt(kTachPin[i]), tachIsr, &tach[i], FALLING);
    windowStart[i] = millis();
  }
  xTaskCreate(taskEntry, "fans", 6144, this, configMAX_PRIORITIES - 3, nullptr);
}

void Fans::applyConfig() {
  std::lock_guard<std::mutex> l(mu);
  for (int i = 0; i < kFans; i++) configureChannel(i);
}

void Fans::taskEntry(void *self) {
  esp_task_wdt_add(nullptr);
  TickType_t t = xTaskGetTickCount();
  for (;;) {
    vTaskDelayUntil(&t, pdMS_TO_TICKS(kTickMs));
    esp_task_wdt_reset();
    static_cast<Fans *>(self)->tick();
  }
}

void Fans::tick() {
  std::lock_guard<std::mutex> l(mu);
  const uint32_t now = millis();
  for (int i = 0; i < kFans; i++) {
    const bool en = settings().ch[i].enabled;
    if (!en && chan[i].speed() != 0) chan[i].setSpeed(0);
    chan[i].update(now, tach[i].total);

    uint32_t d = (uint32_t)(chan[i].duty() * kPwmMax / 100.0f + 0.5f);
    if (d > kPwmMax) d = kPwmMax;
    if (d != lastDuty[i]) {
      ledcWrite(kPwmPin[i], d);
      lastDuty[i] = d;
    }

    if (now - windowStart[i] >= kRpmWindowMs) {
      uint32_t n, first, last;
      portENTER_CRITICAL(&tachMux);
      n = tach[i].winCount;
      first = tach[i].winFirst;
      last = tach[i].winLast;
      tach[i].winCount = 0;
      portEXIT_CRITICAL(&tachMux);
      meter[i].addWindow(n, first, last, (now - windowStart[i]) * 1000u);
      windowStart[i] = now;
    }

    if (chan[i].state() != lastState[i] || chan[i].fault() != lastFault[i] ||
        chan[i].speed() != lastSpeedSeen[i]) {
      // Logging may block on DNS/UDP: never from this task. loop() reports it.
      if (chan[i].fault() && !lastFault[i]) event[i] = 1;
      if (!chan[i].fault() && lastFault[i]) event[i] = 2;
      lastState[i] = chan[i].state();
      lastFault[i] = chan[i].fault();
      lastSpeedSeen[i] = chan[i].speed();
      rev++;
    }
  }
}

void Fans::setSpeed(int ch, int speed) {
  if (speed < 0) speed = 0;
  if (speed > 100) speed = 100;
  std::lock_guard<std::mutex> l(mu);
  for (int i = 0; i < kFans; i++) {
    if ((ch >= 0 && i != ch) || !settings().ch[i].enabled) continue;
    chan[i].setSpeed(speed);
    if (speed > 0) settings().lastOn[i] = speed;
    settings().lastSpeed[i] = speed;
  }
  rev++;
}

void Fans::setPower(int ch, bool on) {
  if (!on) {
    setSpeed(ch, 0);
    return;
  }
  for (int i = 0; i < kFans; i++) {
    if (ch >= 0 && i != ch) continue;
    int s;
    {
      std::lock_guard<std::mutex> l(mu);
      s = settings().lastOn[i];
    }
    setSpeed(i, s);
  }
}

int Fans::presetFor(int speed) {
  for (int i = 0; i < kPresets; i++)
    if (settings().presets[i] == speed) return i;
  return -1;
}

bool Fans::setPreset(int ch, const char *id) {
  for (int i = 0; i < kPresets; i++) {
    if (strcmp(id, kPresetIds[i]) == 0) {
      setSpeed(ch, settings().presets[i]);
      return true;
    }
  }
  return false;
}

FanStatus Fans::status(int ch) {
  std::lock_guard<std::mutex> l(mu);
  FanStatus s;
  s.enabled = settings().ch[ch].enabled;
  s.tach = settings().ch[ch].tach;
  s.speed = chan[ch].speed();
  s.duty = chan[ch].duty();
  s.rpm = meter[ch].rpm();
  s.state = chan[ch].state();
  s.fault = chan[ch].fault();
  return s;
}

uint32_t Fans::pwmHz(int ch) { return ledcReadFreq(kPwmPin[ch]); }

void Fans::logEvents() {
  for (int i = 0; i < kFans; i++) {
    uint8_t e = event[i];
    if (!e) continue;
    event[i] = 0;
    if (e == 1) logf(LOG_WARN, "fan %d stalled", i + 1);
    else logf(LOG_INFO, "fan %d turning again", i + 1);
  }
}

uint32_t Fans::revision() {
  std::lock_guard<std::mutex> l(mu);
  return rev;
}

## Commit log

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2026-08-17 Passproben fuer die drei Lochbleche, tabellengesteuert
    Gemessene Lochblech-Geometrie aller drei Flachheizkoerper. Die Tiefe ist
    jeweils die Summe aus Raendern, Lochfeldern und Mittelsteg - bei allen
    dreien geht die Kette auf:
    A Buero 13 + 39 + 13 = 65 mm, Raster 11,0
    B Wohnzimmer 13 + 75 + 13 = 101 mm, Raster 11,0
    C Esszimmer 17 + 40 + 22 + 40 + 17 = 136 mm, Raster 13,0
    A und B sind dieselbe Bauart in zwei Groessen. C hat als einziger einen
    ungelochten Mittelsteg von 22 mm ueber dem Kanal.
    Korrigiert die aelteren Schaetzwerte: Buero 60 -> 65, Wohnzimmer 100 -> 101,
    Esszimmer 135/137 -> 136.
    Passprobe als Randumgriff-Klammer, die von v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
    [lochblech.csv, passprobe.FCStd, passprobe_A.stl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]
2026-08-17 Halter A: Klammer und Luefterzarge in einem Teil
    Fuer 25-mm-Luefter statt der 15-mm-Slim-Variante - was da ist, wird zuerst
    gemessen. Statt einer Grundplatte mit Durchlass haelt eine Zarge den Luefter
    seitlich; unter ihm ist kein Boden, er blaest direkt aufs Blech. Eine Platte
    waere eine Drosselstelle unmittelbar an der Druckseite und kostet ausserdem
    3 mm Bauhoehe, die im Buero und Esszimmer knapp sind.
    Vier Auflageecken von 2 mm tragen den Luefter, damit er nicht satt auf dem
    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
    [halter_A.stl, halter_A_gedreht.stl, passprobe.FCStd]
2026-08-17 Halter A: Vollsteg durch Rippen ersetzt - Luftweg war zugebaut
    Der Verbindungssteg zwischen Zarge und Klammer lief ueber die volle
    Blechtiefe und verdeckte damit 64 % des Luefteraustritts - ausgerechnet den
    Teil ueber dem Lochfeld, also den einzigen, durch den Luft ueberhaupt
    abfliessen kann. Damit war der Boden wieder da, den die Zarge gerade
    vermeiden sollte.
    Jetzt zwei Rippen von 10 mm auf den ungelochten Randstreifen (13 mm bei A).
    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
    [halter_A.stl, halter_A_gedreht.stl, passprobe.FCStd]
2026-08-17 Druckbarkeit geprueft: alle Ueberhaenge sind Bruecken unter 20 mm
    Nach unten weisende Flaechen in der Drucklage systematisch vermessen. Alle
    sind Bruecken zwischen zwei Zargenwaenden, keine beginnt frei in der Luft:
    Rippen 12 mm Spannweite
    Auflageecken 14 mm
    Klammernasen 2 mm
    Damit kein Stuetzmaterial noetig. Meine erste Zahl (4179 mm2) war die
    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
    [passprobe.FCStd]
2026-08-18 Halter A: flache Zarge ohne Randumgriff, Auflagen bis an die Rippen
    Alles unterhalb der Blechauflage (z<0) entfernt - Backen und Nasen des
    Randumgriffs. Die Befestigung uebernimmt ein eigenes zweites Teil.
    Damit steht das Teil flach auf dem Bett und ist ohne Drehen und ohne
    --no-orient ueberhangfrei: jede Flaeche wird von unten getragen. Die
    gedrehte Druckdatei entfaellt.
    Beim Abschneiden blieben zwei Spalte zwischen Auflageecke und Rippe stehen -
    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
    [halter_A.stl, halter_A_gedreht.stl, passprobe.FCStd]
2026-08-18 Halter A: Luefterauflagen auf Originalmass, Rippen mitverschoben
    Die vier Auflagen sind wieder quadratisch mit z_ecke = 14 mm, statt in Y bis
    an die Rippen gestreckt zu sein.
    Damit endet die vordere Auflage bei y = -3,0. Beide Rippen wandern um
    denselben Betrag mit:
    rippe_dy = z_ecke - a_hinten = -3,0 mm
    Rippe 1 y = -3,0 .. 7,0 schliesst nahtlos an die vordere Auflage an
    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
    [halter_A.stl, passprobe.FCStd]
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2026-08-19 Fixierung: formschluessige Zapfen in den Heizungsschlitzen
    Neues Teil zapfen_A.stl, 2x benoetigt. Hohler Quader, unten offen, dessen
    Aussenmass genau in einen Heizungsschlitz passt:
    Aussen 7,4 x 39,0 mm (a_schlitz - zapfen_spiel x a_lochfeld)
    Hoehe 7,0 mm
    Wandstaerke 2,0 mm
    Kantenradius 2,0 mm an den vier senkrechten Kanten
    Schraubloch 3,5 mm mittig im Deckel
    Weil er den Schlitz an allen vier Seiten ausfuellt, kann er sich weder drehen
    noch laengs wandern - und das nicht gemessene Laengsraster der Schlitze wird
    nicht gebraucht.
    Je ein passendes Loch in beiden Blenden, mittig zur Heizungstiefe (y=32,5)
    und mittig in der Blende. Beide fluchten, eine Schraube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
    [halter_A.stl, passprobe.FCStd, zapfen_A.stl]
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2026-08-21 Fingerschutz-Hauben als eigene Dateien
    Neues Teil je Variante: RadiatorFanGuardSmall/Medium/Large, jeweils in
    eigenem FreeCAD-Dokument. Die Halter-Dateien bleiben unberuehrt - der Schutz
    lag zunaechst faelschlich im selben Dokument und ueberlagerte dort den
    Halter.
    Aufbau: Haube mit Schuerze, die sich ueber die Zarge stuelpt. Der Halt kommt
    aus 0,15 mm Untermass je Seite (0,30 mm gesamt), das auf der ganzen
    Umfangslaenge klemmt - kein Spiel, also kein Vibrationsgeraeusch. Abziehbar.
    Streben laufen laengs zu den Heizungsschlitzen und uebernehmen deren Raster,
    damit sich das Blechmuster optisch nach oben fortsetzt:
    Small Strebe 3,4 Raster 11,0 Luecke 7,60 mm
    Medium Strebe 3,3 Rast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
    [RadiatorFanGuardLarge.FCStd, RadiatorFanGuardLarge.stl, RadiatorFanGuardMedium.FCStd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]
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2026-08-22 Erstlagen-Testmuster: Muehlebrett mit 25 Messpunkten
    Bisher wurde ein echtes Bauteil fuer die Erstlagen-Tests missbraucht. Das
    neue Muster ist dafuer gemacht und zeigt an 25 ueber die Platte verteilten
    Stellen gleichzeitig:
    Schmieren gefuellte Kreisflaeche, 14 mm
    Bahnverschmelzung dieselbe Flaeche - das war das eigentliche Problem
    und ist bei 10 mm kaum zu beurteilen, daher 14
    enge Kurven Kreisring 20 mm bei voller Geschwindigkeit
    scharfe Ecken die zwoelf 90-Grad-Ecken der drei Ringe
    Zur letzten Zeile: echte rechte Winkel fehlten im ersten Entwurf, weil die
    Verbindungen tangential auf die Kreise treffen. Sie stecken aber schon im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
2026-08-22 Messung erste Lage bei z0: Bett hat Delle in der Mitte, keine Kuppel
    24 Kreise des Testmusters mit dem Messschieber vermessen (Nutzer).
    Zentrum im Mittel 0,10 mm, Rand 0,22 mm bei Soll 0,20 - vier Kreise um
    die Plattenmitte kamen mit 0 heraus, die Randmitten mit 0,28-0,30.
    Damit ist die frueher notierte Kuppel widerlegt: die stammte von einem
    132 mm breiten Teil, das den echten Plattenrand nie erreicht hat. Skill
    entsprechend korrigiert.
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2026-08-22 Test bei 0.02: grosse Teile derzeit nicht mit gutem Boden druckbar
    Das rechnerische Optimum wurde gedruckt. Urteil des Nutzers: die meisten
    Kreise haben Luecken zwischen den Bahnen, zwei sind durch zu viel Abstand
    unrund - waehrend die tiefste Stelle bereits auf dem PEI schabte.
    Damit ist die Streuung von rund 20 Hundertsteln breiter als das brauchbare
    Fenster. Ein Offset verschiebt nur, wo das Problem auftritt. Fuer grosse
    Teile fuehrt der Weg ueber die mechanische Justage.
    Ursache der Startfehler war bestaetigt mechanisch: weisses Restfilament
    im Vierwegeverteiler, manuell entfernt.
    [bedtest_z+0.02.stl]
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2026-08-23 Vorzeichenfehler korrigiert: Betthoehe = Offset - Dicke
    Der Nutzer hat den Fehler gefunden: die Karte zeigte hinten links eine
    Senke, obwohl dort die Duese zu nah ist.
    Richtig ist Betthoehe = Offset*100 - Dicke, nicht umgekehrt. Herleitung:
    die Schichtdicke ist der Spalt zwischen Duese und Bett, also
    Dicke = (Nennhoehe + Offset) - Betthoehe. Ein Punkt, der erst bei hohem
    Offset gut kam, brauchte eine hoeher stehende Duese - dort liegt das
    Bett tief.
    Betroffen waren das Plattenprofil, die Karte und die Kapton-Schablonen:
    alle waren punktgespiegelt, das Band waere auf die Beule statt in die
    Senke gekommen.
    Korrigiertes Profil: Beule hinten links und Mitte (4,4 = +14), Senken
    vorn und rechts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
2026-08-24 Druckerkalibrierung ausgelagert: Repo wieder nur Lueftungshalter
    Das Projekt ist fuer die Lueftungshalter da. Wegen anhaltender Probleme
    mit der ersten Lage des Kobra S1 ist es abgedriftet in Bettvermessung,
    Kapton-Shimming und Offset-Kalibrierung - rund 19 MB Testmuster, Karten
    und Auswertungsskripte, die mit dem eigentlichen Zweck nichts zu tun
    haben.
    Alles davon liegt jetzt an seinem Platz:
    Wissen -> Trac, Seite AnycubicKobra, Abschnitt 'Bed levelling and
    z-offset': Messverfahren, Vorzeichenkonvention, Kapton als
    Luftspaltfueller statt Waermeleiter-Ersatz, Arbeitswert
    z-Offset 0.26 und der Befund, dass die PEI-Platte kraeftig
    a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
    [RadiatorFanGuard.FCStd, RadiatorFanLarge.FCStd, RadiatorFanMedium.FCStd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]
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2026-08-24 Place all remaining components and fix MCP-generated schematic corruption
    Placed: 4x fan headers (J2-J5), 4x 10k tach pull-ups (R1-R4), 4x 1k PWM
    series resistors (R5-R8), 4x 330R tach series resistors (R9-R12),
    barrel jack reverse-polarity protection chain (J1/D1/F1/C1), and the
    12V->5V regulator (U2, AMS1117-5.0 via base symbol AP1117-15) with
    input/output caps.
    Also fixed real defects in every component the kicad-mcp-server tool
    placed, discovered by bisecting against kicad-cli (which the tool's own
    "success" messages never actually validate against):
    - add_component_from_library embeds an invalid (uuid ...) sub-field
    inside each property block on placed instances -- not valid KiCad 10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
    [fan-controller.kicad_sch]
2026-08-24 Wire the complete fan controller schematic
    All 22 nets connected and verified pin-by-pin against the netlist:
    Power: J1 -> D1 (reverse-polarity) -> F1 (polyfuse) -> +12V_PROT
    +12V_PROT -> C1, U2 (AMS1117-5.0) -> +5V -> C2, XIAO VBUS
    XIAO 3V3_OUT -> four 10k tach pull-ups
    Fans: each J: pin1 GND, pin2 +12V_PROT, pin3 tach, pin4 PWM
    tach -> 10k pull-up to 3V3, then 330R series -> XIAO
    XIAO -> 1k series -> fan PWM
    GPIO: FAN1 D1/D2 FAN2 D3/D4 FAN3 D5/D6 FAN4 D7/D10
    D0, D8, D9 left free (ESP32-C3 strapping pins)
    Wired as per-pin stubs plus net labels rather than routed traces, so
    there are no shared routing lanes and therefore no co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
    [fan-controller.kicad_sch]
2026-08-24 Import footprints into PCB with nets and initial layout
    All 23 footprints loaded from their libraries with 75 pad-to-net
    assignments taken from the exported netlist, plus an 80x60mm Edge.Cuts
    outline. Arranged by function as a starting point for manual layout:
    top left J1 -> D1 -> F1 -> C1, with U2/C2 below
    centre U1 (XIAO socket)
    right edge J2-J5, each beside its pull-up / PWM / tach resistors
    Done via the pcbnew Python API: kicad-cli has no schematic-to-board
    update command, and KiCad 10's Python bindings don't expose netlist
    reading, so nets and pads were wired up directly.
    DRC: no clearance or overlap violations. The 43 unconnected items are
    the expected ratsnest on an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
    [fan-controller.kicad_pcb]
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2026-08-25 Fold every schematic step into generate.py; swap fan pin pairs
    generate.py is now the only command needed to rebuild the schematic. It runs
    the full sequence, because each step used to be separate and every one of them
    was forgotten at least once:
    1. reposition symbols and redraw all nets (validated before writing)
    2. repair structural defects (was fix_sch.py, now deleted)
    3. re-attach PWR_FLAGs and no-connects (was an ad-hoc snippet, retyped
    by hand three times)
    4. verify the netlist against netplan.py (was a separate audit)
    Step 4 matters most: ERC cannot catch a wire landing on the wrong real pin,
    since that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
    [fan-controller.kicad_pcb, fan-controller.kicad_sch]
2026-08-26 Route the board: ground plane, wider power nets, jack on the edge
    The PCB is now fully routed. 167 tracks, 7 vias, no unconnected pads.
    Layout
    Board shrunk from 80 x 60 mm to 72.9 x 25.0 mm, fitted 1mm clear of all
    copper. J1 sits on the right end opposite the XIAO with its flange on the
    board edge, so the 3.5mm barrel protrudes as a panel-mount jack should.
    Getting there took two goes: the flange initially sat 1.9mm inboard of the
    edge, making the plug look adrift. Moving the plug pocket (J1, F1, D1 plus
    9 tracks) 1.8mm inward fixed it. 3mm was requested but drives F1's pad and
    the +12V_IN wire into the +12V_PROT trunk at x=91.5; 1.8mm is the limit
    before that clash. Only t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
    [fan-controller.kicad_pcb, fan-controller.kicad_sch]
2026-08-26 Generate the fabrication package
    make_fab.sh produces everything a fab house needs, in one command:
    gerbers, Excellon drill, BOM and pick-and-place, zipped as
    fab/fan-controller-fab.zip (15 files, 194 KB).
    Board: 72.9 x 25.0 mm, 2 layers, min track/clearance 0.2mm, min drill
    0.3mm, 42 holes across 5 sizes. Quantity 20, assembled.
    Three things needed handling that the default exports get wrong:
    Gerbers must name their layers explicitly. A bare `kicad-cli pcb export
    gerbers` writes every layer - the first run shipped a 152KB User_Eco1.gbr
    containing the review markers used during layout.
    The four fan headers would not group in the BOM. Their Values are
    FAN1..FAN4 (which channel e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
    [fan-controller-bom.csv, fan-controller.kicad_pcb, fan-controller.kicad_sch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]
2026-08-26 Document ordering options with an assembly cost estimate
    Assembled (JLCPCB, 20 off) comes out at roughly 95 EUR total, ~4.70 per
    board, estimated from their published rates. Through-hole dominates the
    labour: $3.50 hand-soldering fee plus $0.0173/joint, and this board has 35
    THT joints each - about half the total labour cost. That is the lever if a
    real quote comes back high.
    The cheap panelised route does not fit as hoped. Four boards stacked is
    4 x 25.0 = exactly 100.0mm with zero gap, and 3-across-plus-1-on-top is
    75 x 97.9mm before gaps - both over once routing gaps are added. The board
    cannot shrink either: the +12V_PROT traces already sit at exactly 0.5mm
    from both edges, the design-r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
2026-08-26 Record decision: order fully assembled
    Priced an SMD-only middle option at ~68 EUR against ~95-100 for full
    assembly. The ~33 EUR gap is only ~15 EUR of real labour once component
    sourcing is separated out, which does not justify 700 hand-soldered joints.
    Fixed costs (shipping ~23, bare PCBs ~18) rule out getting near 50 EUR at
    this quantity either way.
    Decision is contingent on the real quote landing near the estimate.
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2026-08-31 Fix BOM and CPL column format for JLCPCB import
    Die CPL wurde beim Hochladen abgelehnt. Ursache waren nicht die Werte,
    sondern die Kopfzeile: kicad-cli exportiert Ref,Val,Package,PosX,PosY,Rot,
    Side - JLCPCB erwartet Designator,Mid X,Mid Y,Layer,Rotation, also andere
    Namen UND andere Reihenfolge. Zusaetzlich will JLCPCB "Top"/"Bottom" statt
    "top"/"bottom" und Masse mit Einheitensuffix.
    make_cpl.py schreibt die Datei jetzt entsprechend um. Die Koordinaten waren
    bereits richtig (Ursprung linke untere Platinenecke, mm).
    Die BOM hatte dasselbe Problem und ist auf Comment,Designator,Footprint,
    LCSC Part # umgestellt. Dabei entfallen Qty, MPN/Supplier und die
    DNP-Spalte; die Kanalnamen (FAN1..FA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
    [fan-controller-bom.csv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]
2026-08-31 Fix BOM/CPL designator mismatch rejected by JLCPCB
    JLCPCB meldete beidseitig fehlende Designatoren. Zwei Ursachen:
    Bereichsschreibweise. Die BOM fasste Designatoren zu "R1-R4", "J2-J5",
    "R9-R12" zusammen, die CPL listet sie einzeln. JLCPCB gleicht beide Dateien
    designatorweise ab und kennt keine Bereiche - daher "R2,R3,R4,... don't
    exist in the BOM file". collapse() schreibt jetzt vollstaendige Kommalisten.
    Erfundene Designatoren fuer die Fassungen. U1-SKT1/U1-SKT2 gibt es auf der
    Platine nicht: die Buchsenleisten haben kein eigenes Schaltplan-Symbol, ihre
    Loecher sind die 14 Durchsteckpads des XIAO-Footprints. Ohne CPL-Eintrag
    weist JLCPCB die Zeile zurueck.
    Aufgeloest, indem U1 nicht me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
    [fan-controller-bom.csv, fan-controller.kicad_pcb, fan-controller.kicad_sch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]
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2026-08-31 Add PCBWay export format; document the rotation issue
    Zur Fehlplatzierung in JLCPCBs Vorschau: die liegt nicht an unseren Dateien.
    Die Rotationswerte in der CPL stimmen bauteilweise exakt mit der Platine
    ueberein, nachgeprueft. Ursache ist die bekannte Unstimmigkeit zwischen
    KiCad und JLCPCB - beide verwenden fuer dieselben Gehaeuse unterschiedliche
    Nullstellungen, besonders bei SOT und polarisierten Teilen.
    Die Community loest das ueber Korrekturtabellen (Bouni/kicad-jlcpcb-tools).
    Bewusst nicht eingebaut: der richtige Versatz haengt vom konkret gewaehlten
    Katalogteil ab, und ein falscher Wert dreht das Bauteil um 180 Grad. Bei D1
    und U2 waere die Platine dann Ausschuss. Die Vorschau zeigt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
    [fan-controller-bom-pcbway.csv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]
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2026-08-31 PCBWay BOM in English
    Die Sourcing-Hinweise werden bei PCBWay von Sachbearbeitern gelesen -
    Deutsch hilft dort niemandem. THT_SPEC und die Note-Praefixe sind jetzt
    englisch, ebenso U1s Value-Text (der aus make_bom.py stammt und damit auch
    in der JLCPCB-Datei landet).
    Inhaltlich unveraendert, insbesondere die beiden Punkte, die sonst
    schiefgehen: C1 als "THROUGH-HOLE (not SMD)" und U1 mit "2x female header
    per board - do NOT fit the module itself".
    Bei den THT-Positionen steht im Value-Feld jetzt nur noch der Teilename;
    die Details standen vorher doppelt dort und in der Note.
    Geprueft: keine deutschen Reste mehr, BOM und CPL weiterhin deckungsgleich
    bei 23 Designatoren.
    [fan-controller-bom-pcbway.csv]
2026-08-31 Show the socket count in U1's Value field
    Frage war, ob U1 statt Qty 1 besser Qty 2 bekommt, weil dort zwei
    Buchsenleisten sitzen.
    Bewusst nicht: die Qty-Spalte korrespondiert mit der Designatorliste (ein
    Designator = 1, vgl. J2-J5 mit vier Designatoren und Qty 4), und die CPL
    hat fuer U1 genau einen Eintrag mit einer Position und einer Drehung. Qty 2
    gegen einen CPL-Eintrag waere widerspruechlich - genau solche
    Inkonsistenzen hat JLCPCB schon abgelehnt.
    Das Problem dahinter bleibt: ein Footprint, zwei physische Bauteile. Das
    laesst sich in der Qty-Spalte nicht sauber abbilden. Der Faktor steht
    deshalb jetzt im Value-Feld ("2x 1x7 female header 2.54mm"), wo ein
    Einkaeufer zuerst hinsieht,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
    [fan-controller-bom-pcbway.csv]
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2026-09-05 PCBWay BOM: Qty means parts per board
    U1 is one designator but takes two 1x7 female headers. It went out as
    Qty 1 with the factor written into the Value field and the note; PCBWay
    corrected it to Qty 2. The calculation follows the column, not the prose,
    so QTY_PER_FOOTPRINT now multiplies into Qty and the counts elsewhere are
    gone - a "2x" in the Value next to Qty 2 reads as four.
    [fan-controller-bom-pcbway.csv]
2026-09-06 Enclosure: snap-fit case generated from the board geometry
    Two-part PETG case, 78.3 x 30.4 x 24.1 mm, no screws: four cantilever
    latches on the lid engage pockets in the tray walls.
    The board dimensions are not typed in. extract_geometry.py reads them from
    the .kicad_pcb through pcbnew and writes board_params.scad - deriving the
    footprint rotations by hand from the s-expressions gave a mirrored layout
    here once already, and a barrel jack facing the wrong way would only show
    up on the finished print.
    check_fit.py verifies what a render does not show. It caught a snap pocket
    that cut clean through the wall and a latch nose sitting 2 mm below its
    pocket, neither visible in the preview. The mo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
    [board_params.scad, case.scad, fan-controller-case-guide.stl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]
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2026-09-06 Enclosure: show the light guide with the lid
    The lid view was the print orientation of the lid alone, so the one part
    that gets printed in a different material was missing from it. New
    view-only part lid_guide lifts the guide off its opening; part="lid" is
    left alone because that one is the STL export.
    [case.scad]
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2026-09-10 result.json ist Slicer-Abfall, nicht Quelltext
    Die Datei sagt nur 'return_code 0' zum letzten Export und wurde in
    97963fc versehentlich mitgenommen. Aus der Versionierung genommen und
    kuenftig ignoriert.
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2026-10-04 fan-remote: Home-Assistant-Entitaeten auf Wunsch neu anlegen, Updater-Abbruch behoben
    * unique_ids und Discovery-Themen tragen eine Generationsnummer (haGen im NVS,
    0 = wie bisher). POST /api/discovery mit recreate=1 und die Schaltflaeche in
    den Einstellungen entfernen die alten Entitaeten, warten 2,5 s und legen sie
    unter der naechsten Generation neu an; die Entitaets-Ids entstehen dann aus
    den aktuellen Namen. Noetig, weil HA einer zurueckkehrenden unique_id ihre
    alte Id wiedergibt (geprueft: Loeschen und neu Senden allein aendert nichts)
    * Firmware-Upload: bricht die Verbindung mitten im Transfer ab, blieb der
    Updater belegt und jeder weitere Versuch scheiterte mit 'No Error'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
2026-10-04 fan-controller: scripts into scripts/, run from anywhere; docs in English; component README
    The fab package moved into fan-controller/fab and the build log into
    fan-controller/docs when the repository was reorganised. The generator and
    export scripts now live in scripts/ and resolve their paths from their own
    location. Fab docs translated to English and corrected (10 boards ordered, not
    20); fan header and PWM-at-reset caveats documented; vendored Seeed library
    attributed (CC BY-SA 4.0).
    [draw.py, generate.py, layout.py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]
2026-10-04 fan-housing: rename from enclosure, English docs and comments
    case.scad is now fan-housing.scad, STLs and renders follow the new name.
    extract_geometry.py and check_fit.py resolve paths from their own location;
    export_stl.sh regenerates the STLs. Outer height corrected to 24.2 mm in the
    docs (3.1 mm lid).
    [board_params.scad, case.scad, fan-housing-guide.stl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]
2026-10-04 fan-mount: rename from fan-stand, English docs and comments
    Docs moved to docs/ (requirements, measurements, design notes, primer),
    cad/README replaced by design-notes with a glossary of the German parameter
    names, scripts write next to the opened document instead of a fixed path,
    lochblech.csv became radiator_sheets.csv with English columns.
    [lochblech.csv, radiator_sheets.csv]
2026-10-04 fan-remote: random admin password per build tree, tag-scoped version
    config.ini.template carries @RANDOM@ again; the first build replaces it with a
    random password and prints it. git describe only considers fan-remote-v* tags
    now that the repository holds several components. Docs: private references
    removed, /api/wake documented, link to the board README.
    [devices.csv]
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2026-10-04 fan-remote: replace only the password line of the template, not the comment
2026-10-04 fan-housing: 4 mm taller, sharp inside, tighter openings, mouse ears
    Socketed XIAO sits 4 mm higher than assumed: h_socket 12.5, inner height 19.
    Cable notches 1 mm deep, USB-C a closed 4 mm window centred on the receptacle,
    jack opening 1.4 mm narrower per side, inside corners sharp like the board,
    fit 0.3 -> 0.4 mm. Tray STL carries four one-layer mouse ears against lifting
    at the long ends; docs and renders updated.
    [fan-housing-guide.stl, fan-housing-lid.stl, fan-housing-tray.stl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]
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2026-10-04 fan-remote: no mDNS; the board is found by its DHCP hostname
    mDNS and ArduinoOTA's mDNS are off. Docs, upload ports and the Home Assistant
    configuration URL use the plain device name (fan-control-N), which the board
    announces in its DHCP request and local DNS resolves.
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2026-10-04 Revert "Docs: at most 2 fans per channel (8 per board)"
    This reverts commit b3352fb18ca3e8d0a5d24a4d4cc4693a42660c89.
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2026-10-04 fan-remote 1.0.0: per-device page colour, status LED with health pattern and night dimming
    The page's base hue comes from the device number (red and green stay the signal
    colours). Boards with a LED (XIAO ESP32-C6: yellow user LED) show fans on/off and a
    health signal (stalled fan, no WiFi/MQTT/clock) as steady / flash / blink patterns, PWM
    dimmed by day and night or off completely. /api/netstatus reports health and LED state;
    settings, spec, user and admin docs updated.
    [main.cpp]
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
